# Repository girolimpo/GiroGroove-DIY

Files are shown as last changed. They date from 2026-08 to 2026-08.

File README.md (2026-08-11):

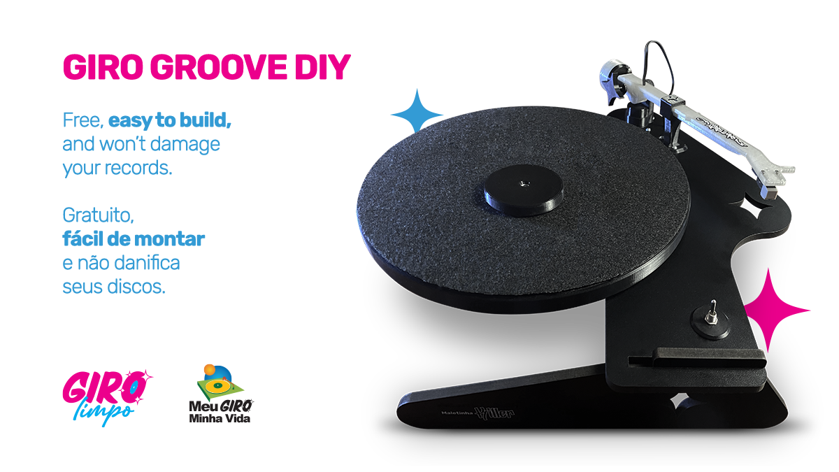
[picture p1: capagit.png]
Giro Groove DIY


# Giro Groove DIY
**A Giro Limpo project — [girolimpo.com.br](https://girolimpo.com.br)**

**A simple, functional and easy-to-build DIY turntable.**

The GiroGroove DIY is a project developed by **Giro Limpo** for anyone who wants to build their own turntable.

## Files

The files provided in this repository are final production-ready files.

* **BOM** — bill of materials and parts list
* **STL** — 3D printing files
* **CORTE_LASER** — PDF files for laser cutting
* **STROB_PROTRACT** — PDF file for cartridge calibration and turntable speed

## Assembly Tutorial

Follow the complete step-by-step assembly tutorial on YouTube:

**[▶ WATCH THE FULL TUTORIAL](LINK_TO_YOUTUBE)**

## Important

The video tutorial contains the complete assembly instructions for the project.

We recommend watching the tutorial before starting the build.

## License

This project is licensed under:

**Creative Commons Attribution-NonCommercial-ShareAlike 4.0 International (CC BY-NC-SA 4.0)**

You may copy, modify and build the project for non-commercial purposes, provided that proper credit is given and adaptations are distributed under the same license.

**Commercial use and sale of the project or its parts are not permitted.**

© Giro Limpo - Wesley de Castro - Brazil

---

# Giro Groove DIY
**Um projeto Giro Limpo — [girolimpo.com.br](https://girolimpo.com.br)**

**Um toca-discos DIY simples, funcional e fácil de montar.**

O GiroGroove DIY é um projeto desenvolvido pela **Giro Limpo** para quem quer construir seu próprio toca-discos.

## Arquivos

Os arquivos disponibilizados neste repositório são finais e estão prontos para produção.

* **BOM** — lista de materiais e peças
* **STL** — arquivos para impressão 3D
* **CORTE_LASER** — arquivos PDF para corte a laser
* **STROB_PROTRACT** — arquivo PDF para calibragem da cápsula e velocidade do prato

## Tutorial de montagem

Siga o passo a passo completo de montagem no YouTube:

**[▶ ASSISTA AO TUTORIAL COMPLETO](LINK_DO_YOUTUBE)**

## Importante

O tutorial em vídeo contém todas as instruções necessárias para a montagem do projeto.

Recomendamos assistir ao tutorial antes de iniciar a construção.

## Licença

Este projeto está licenciado sob:

**Creative Commons Attribution-NonCommercial-ShareAlike 4.0 International (CC BY-NC-SA 4.0)**

Você pode copiar, modificar e produzir o projeto para fins não comerciais, desde que atribua os devidos créditos e mantenha a mesma licença em eventuais adaptações.

**O uso comercial e a venda do projeto ou de suas partes não são permitidos.**

© Giro Limpo - Wesley de Castro - Brasil

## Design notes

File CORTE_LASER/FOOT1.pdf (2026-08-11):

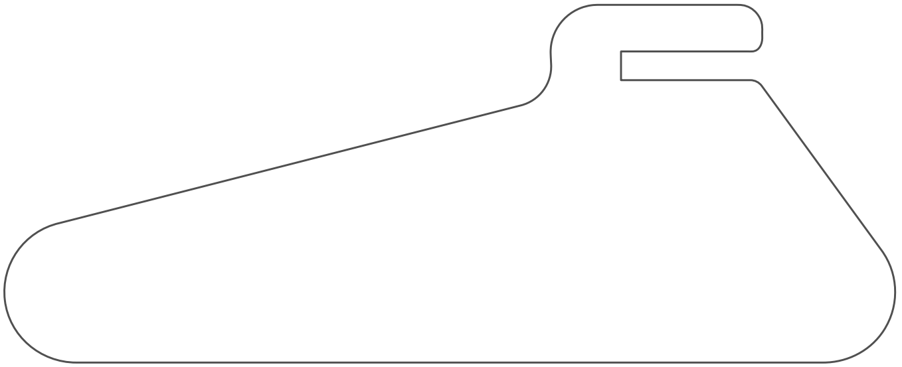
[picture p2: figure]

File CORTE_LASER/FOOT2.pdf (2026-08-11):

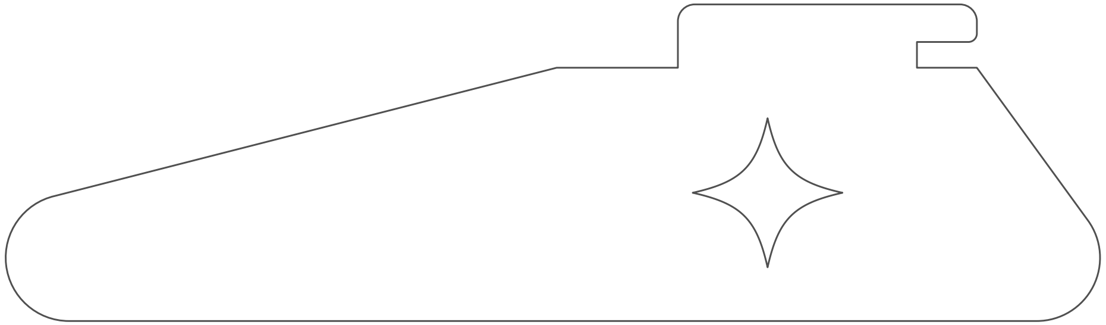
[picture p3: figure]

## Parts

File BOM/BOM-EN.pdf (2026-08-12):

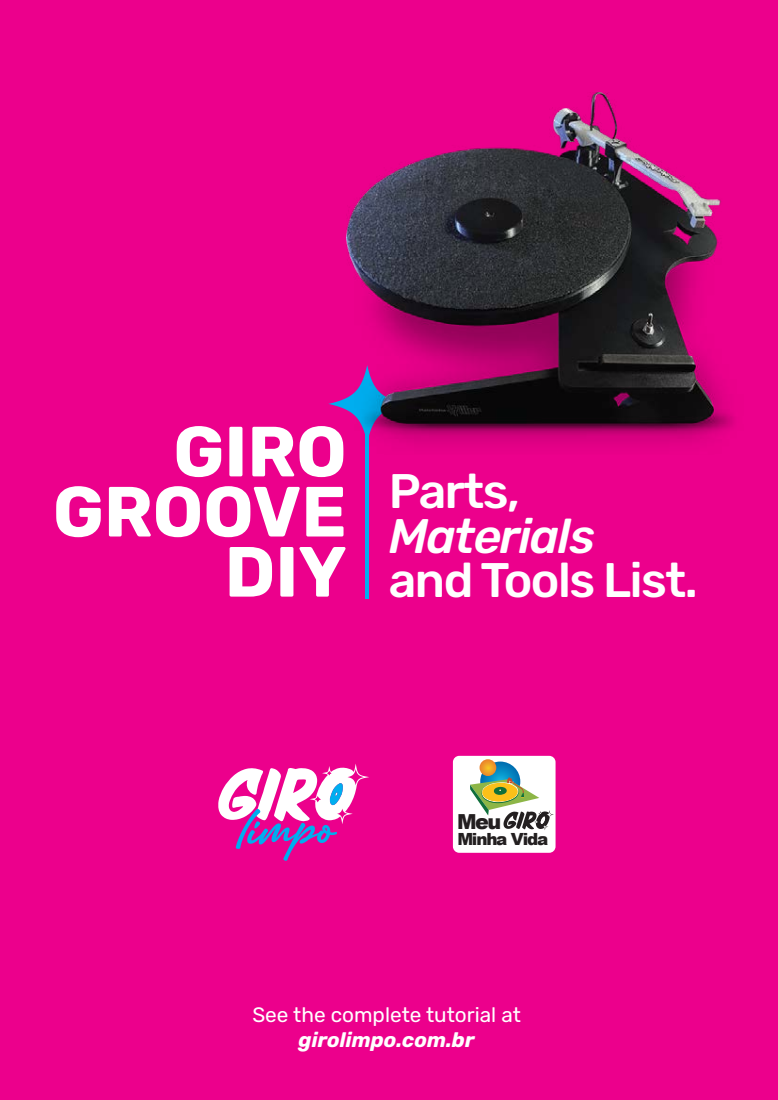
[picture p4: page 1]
Minha Vida; Meu; GIRO GROOVE DIY; Parts, Materials and Tools List.

See the complete tutorial at
girolimpo.com.br

# 3D PRINTER

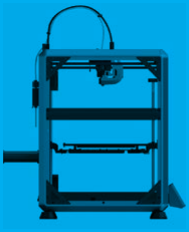
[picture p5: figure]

Recommended print area: approximately 30 × 30 cm
The project includes parts that need to be produced using 3D printing. A printer with a print area of approximately 30 × 30 cm will meet the project's needs well.
Don't have a 3D printer?
Don't worry. You probably know someone who does.
That friend who bought a 3D printer and now prints everything that comes along can finally be useful. Or look for a 3D printing service in your city — you don't need to own a machine to build your Giro Groove.

# LASER CUTTING

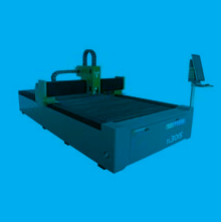
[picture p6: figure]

Some parts of the project are made from laser-cut MDF.
You don't need to buy a laser cutter — unless you're planning to start a business in this field.
Look for a laser cutting service in your city that works with MDF. Many companies accept digital files and deliver the parts already cut.
Tip: Search for “MDF laser cutting + your city name.”

# WIRE CUTTERS

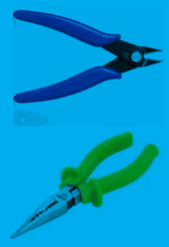
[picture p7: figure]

Used to cut wires and terminals and to make small finishing adjustments during assembly.

# NEEDLE-NOSE PLIERS

Very useful for holding components, bending terminals, and reaching hard-to-access areas.

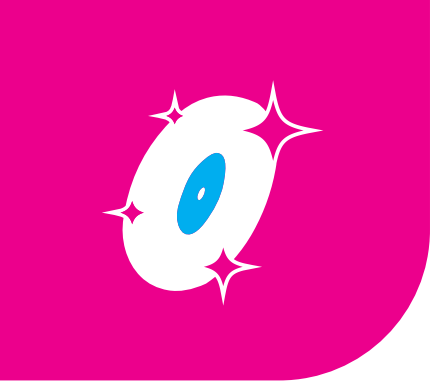
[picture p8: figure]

# Tools

You don't need a professional workshop to build the Giro Groove DIY. Some tools are essential, while others simply make the work easier — and some you can probably borrow, improvise, or easily find in your area.

# SOLDERING IRON

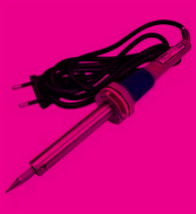
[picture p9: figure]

A simple 30 W or 40 W soldering iron is more than enough for this project.
There are only a few soldering points, and they are quite simple. Never soldered before?
This could be a great opportunity to learn. But if you prefer, any electronics repair shop can do the job in just a few minutes. Since there are only a few connections, the cost is usually very low.

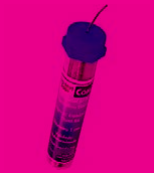
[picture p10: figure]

# ELECTRONICS SOLDER

Use solder specifically intended for electronics.
It will only be used for the electrical connections in the project.

# SCREWDRIVERS AND HEX KEYS

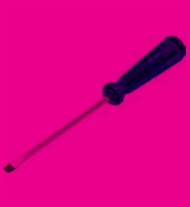
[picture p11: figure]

You will need the tools that match the screws you choose for the project.
They can be:
Flat-head screwdriver
Phillips screwdriver
Allen key
Or, if you prefer, a power screwdriver/drill with the corresponding bits. Besides speeding up the assembly, it also saves your arm some work.


# RUBBER MALLET

Not an essential tool, but it can be very helpful for some fittings, allowing you to apply light impacts without damaging the 3D-printed parts or the MDF.
If you don't have one, you will probably be able to assemble the project just fine without it.

correct model!

EG530SD-3F Turntable Motor

Flat drive belt for vinyl record

turntables, 5 mm × 190 mm
(measurement taken with
the belt folded in half).

# Electronic Components and Other Materials

Let's start with the MDF. The parts must be cut exactly to the dimensions specified in the original files available on GitHub, with no changes to their size. The MDF must be 4 mm thick.
You can use coated MDF, which provides a better finish and eliminates the need for painting. If you choose regular MDF, that's fine too: after cutting, you will only need to apply paint or whatever finish you prefer.
The 3D printing filament can be virtually any type, but for this project we recommend PETG because of its greater strength and durability. The color is entirely up to you. Choose the one that best matches your Giro Groove.
Most of the electronic components and other materials are easy to find. You can look for them at electronics stores, Mercado Livre, AliExpress, eBay, or any other supplier you prefer.
The following list is fully illustrated, with photos and specifications for each component, specifically to make identification easier and help you avoid buying a different part than the one required for the project.

# 3D Printing Filament and MDF

Make sure you
get the

DB15 female solder connector.; 12V 1A 12W power supply with P4 output.

AT3600L Moving Magnet Cartridge with Stylus for Turntables, or any other compatible cartridge you may have available. The better the cartridge, the better the sound quality of your Giro Groove DIY.

6202ZZ bearing, 15 × 35 × 11 mm.

608ZZ bearing, 8 × 22 × 7 mm.

625ZZ bearing, 5 × 16 × 5 mm.

DC-022 female P4 power jack, 5.5 × 2.1 mm, threaded.


Mini DPDT toggle switch, 6-pin, ON-OFF-ON.

2 metal male RCA plugs/connectors.

1 meter of Philips 2 × 0.50 mm² stereo audio cable.


60 cm of Philips 2 × 0.18 mm² stereo audio cable, or thinner.

12 × 3.0 × 12 mm self-tapping screws.

with 2 × 1/4" nuts.

1/4" × 1 1/4" hex bolt, black oxide, fully threaded,

1/4" × 5/8" hex bolt, black oxide.

25 machine screws with slotted, Allen, or Phillips heads. The head type does not matter, as long as you have the corresponding tool. What matters is that the screws are 15 mm long and, most importantly, have a 3 mm diameter.

### 2 M2.5 × 10 mm machine screws with M2.5 nuts for

cartridge mounting. If you cannot find the screws, you can use double-sided tape to attach the cartridge
to the headshell.

M18 hex nut for making the counterweight.

4 mm heat-shrink tubing.

# And for the adjustments?

### 50 cm of automotive carpet or felt for

making the slipmat.

Super glue, epoxy, Super Bonder, or another similar adhesive.


Stroboscopic disc for speed adjustment or a smartphone app to adjust the platter RPM.


Protractor alignment gauge for cartridge alignment, also available for download in the GitHub folder.

With all the components and materials gathered, don't forget the 3D-printed parts. There are 20 printed parts in total that make up the project.
You will also need the 3 MDF pieces, already cut according to the original files. Everything ready? Then it's time to get your hands dirty.
Visit girolimpo.com.br and head over to the Giro Limpo YouTube channel to follow the complete Giro Groove DIY tutorial.
And while you're there, take a moment to check out our store. If you'd like to support the project and help keep new projects like this coming, you can also contribute via PIX or PayPal.
And don't forget to like and follow the channel. It helps keep the project spinning.

And now, it's time to get started.

## girolimpo.com.br

© 2026 GIRO LIMPO. Wesley de Castro. All rights reserved.

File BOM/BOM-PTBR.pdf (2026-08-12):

Minha Vida; Meu; GIRO GROOVE DIY; Lista de peças, materiais e ferramentas

Veja o Tutorial completo
no site girolimpo.com.br

# IMPRESSORA 3D


Área de impressão recomendada: aproximadamente 30 × 30 cm O projeto possui peças que precisam ser produzidas em impressão 3D. Uma impressora com uma área de impressão de aproximadamente 30 × 30 cm atende bem às necessidades do projeto.
Não tem uma impressora 3D?
Calma. Você certamente conhece alguém que tem.
Aquele amigo que comprou uma impressora 3D e agora imprime tudo o que aparece pode finalmente ser útil. Ou procure um serviço de impressão 3D na sua cidade — você não precisa ter uma máquina em casa para construir o seu Giro Groove.


# CORTE A LASER

Algumas peças do projeto são produzidas em MDF cortado a laser. Você não precisa comprar uma máquina de corte dessa — a menos que esteja planejando abrir um negócio nesse ramo. Procure na sua cidade por um bureau de corte a laser que trabalhe com MDF. Existem muitas empresas que recebem os arquivos digitalmente e entregam as peças já cortadas. Dica: pesquise por “corte a laser MDF + nome da sua cidade.

# ALICATE DE CORTE


Utilizado para cortar fios, terminais e realizar pequenos acabamentos durante a montagem.

# ALICATE DE PONTA

Muito útil para segurar componentes, dobrar terminais e alcançar locais de difícil acesso.


# Ferramentas

Você não precisa de uma oficina profissional para construir o Giro Groove DIY. Algumas ferramentas são indispensáveis, outras apenas facilitam o trabalho — e algumas você provavelmente consegue emprestadas, improvisadas ou encontra facilmente na sua cidade.

# FERRO DE SOLDA


Um ferro de solda simples de 30 W ou 40 W já atende perfeitamente ao projeto.
As soldagens são poucas e bastante simples.
Nunca soldou antes?
Essa pode ser uma ótima oportunidade para aprender. Mas, se preferir, qualquer oficina de eletrônica faz esse serviço em poucos minutos e, por serem apenas algumas conexões, o custo costuma ser bem baixo.


# SOLDA PARA ELETRÔNICA

Utilize solda de estanho própria para eletrônica.
Ela será usada apenas nas conexões elétricas do projeto.

# CHAVES DE MONTAGEM


Você precisará das chaves compatíveis com os parafusos escolhidos para o projeto.
Pode ser:
Chave de fenda
Chave Phillips
Chave Allen
Ou, se preferir, uma parafusadeira com os bits correspondentes. Além de agilizar a montagem, ela ainda poupa um pouco o braço.


# MARTELO DE BORRACHA

Não é uma ferramenta obrigatória, mas ajuda bastante em alguns encaixes, permitindo aplicar pequenos impactos sem danificar as peças impressas ou o MDF.
Se não tiver um, provavelmente conseguirá montar o projeto da mesma forma.


Motor para toca-discos
EG530SD-3F.

Correia de transmissão plana para

toca-discos de vinil, 5 mm × 190 mm (medida feita com a correia dobrada).

# Componentes eletrônicos e outros materiais

Começamos pelo MDF. As peças devem ser cortadas exatamente nas medidas dos arquivos originais disponibilizados no GitHub, sem alterações de tamanho. O MDF deve ter 4 mm de espessura.
Você pode utilizar MDF revestido, o que proporciona um acabamento melhor e evita a necessidade de pintura. Se optar pelo MDF comum, não tem problema: depois do corte, será necessário apenas algum tipo de pintura ou acabamento de sua preferência.
O filamento utilizado na impressão 3D pode ser de praticamente qualquer tipo, mas para este projeto recomendamos o PETG pela sua maior resistência e durabilidade. A cor fica totalmente a seu critério. Pode escolher a que mais combina com o seu Giro Groove.
Os componentes eletrônicos e demais materiais são, em sua maioria, fáceis de encontrar. Você pode procurar em lojas de eletrônica, Mercado Livre, AliExpress, eBay ou em outros fornecedores de sua preferência.
A lista a seguir é toda ilustrada, com fotos e especificações dos componentes, justamente para facilitar a identificação e evitar que você compre uma peça diferente da necessária para o projeto.

# Filamento 3D e MDF

Atenção para
o modelo correto!

Conector DB15 fêmea para solda.

Cartucho magnético móvel AT3600L com agulha para toca-discos Audio Technica ou alguma outra que você tenha disponível. Quanto melhor o cartucho melhor a qualidade sonora do seu Giro Groove DIY.

Fonte de alimentação 12 V, 1 A, 12 W, com saída P4.

Rolamento 6202ZZ, 15 × 35 × 11 mm.

Rolamento 608ZZ, 8 x 22 x 7 mm.

Rolamento 625ZZ, 5 x 16 x 5 mm.

Conector jack P4 fêmea DC-022, 5,5 × 2,1 mm, com rosca.


Mini chave toggle switch DPDT, 6 pinos, ON-OFF-ON.

2 plugs RCA macho metálicos (conectores RCA).

### 1 metro de cabo de áudio estéreo duplo

Philips 2 × 0,50 mm².


### 60 centímetros de cabo de áudio estéreo duplo Philips

2 × 0,18 mm² ou mais fino.

12 parafusos de rosca soberba 3,0 × 12 mm.

de 2 porcas 1/4"

Parafuso sextavado 1/4" × 1 1/4", preto oxidado, com rosca em todo o comprimento e acompanhado

Parafuso sextavado 1/4" × 5/8", preto oxidado.

25 parafusos tipo máquina, com cabeça fenda, Allen ou Phillips. O tipo de cabeça não importa, desde que você tenha a chave correspondente.
O importante é que o parafuso tenha 15 mm de comprimento e, principalmente, 3 mm de diâmetro.

2 parafusos de máquina M2,5 × 10 mm, com porcas M2,5, para fixação da cápsula. Caso não encontre os parafusos, você pode utilizar fita dupla face para fixar a cápsula
à headshell.

Porca sextavada M18 para confecção do contrapeso.

# E para fazer os ajustes?

### 50 cm de carpete automotivo ou feltro para

a confecção do slipmat.

Supercola, epóxi, Super Bonder ou outro adesivo semelhante.

Espaguete termo retrátil de 4 mm.


Disco estroboscópico para ajuste da velocidade ou aplicativo para smartphone para ajustar
o RPM do prato.


Régua Protractor para alinhamento da cápsula, também disponível para download na pasta do GitHub.

Com os componentes e materiais reunidos, não esqueça das peças impressas em 3D. Ao todo, são 20 peças que fazem parte do projeto.
Você também precisará das 3 peças de MDF, já cortadas conforme os arquivos originais.
Tudo pronto? Então é hora de colocar a mão na massa.
Acesse o site girolimpo.com.br e entre no canal do Giro Limpo no YouTube para acompanhar o tutorial completo do Giro Groove DIY.
E já que você está por lá, aproveite para conhecer a nossa loja. Se quiser apoiar o projeto e ajudar a manter novos projetos como este acontecendo, você também pode contribuir através do PIX ou PayPal.
E não esqueça de curtir e seguir o canal. Isso ajuda o projeto a continuar girando.

# E agora, é hora de começar

## girolimpo.com.br

© 2026 GIRO LIMPO. Wesley de Castro. Todos os direitos reservados.

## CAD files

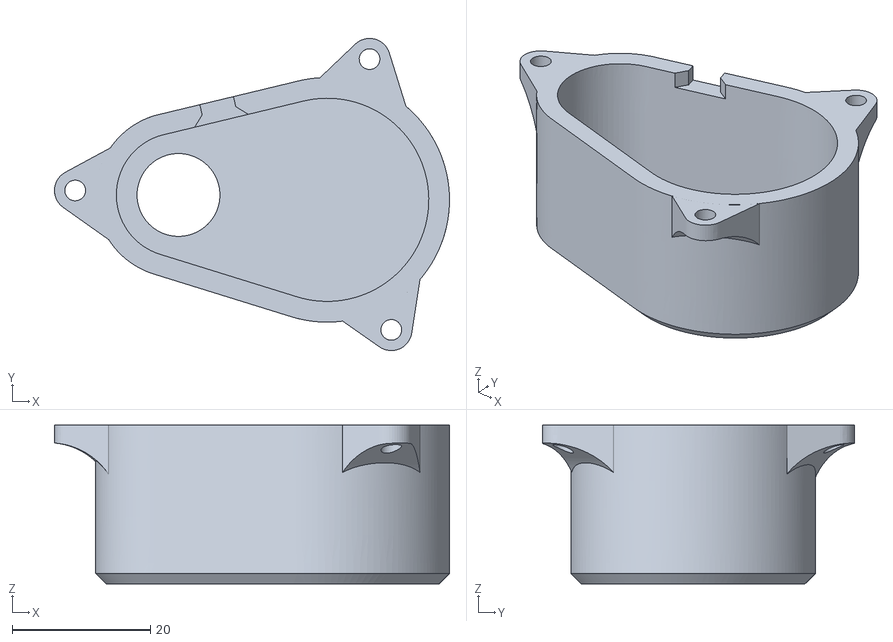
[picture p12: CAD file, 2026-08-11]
STL/powerbox.stl
57.2 x 45.2 x 23.0

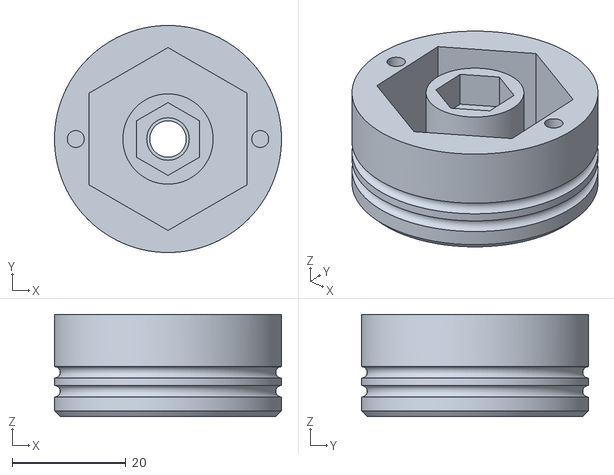
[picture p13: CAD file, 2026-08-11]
STL/contrapeso.stl
40.0 x 40.0 x 18.0

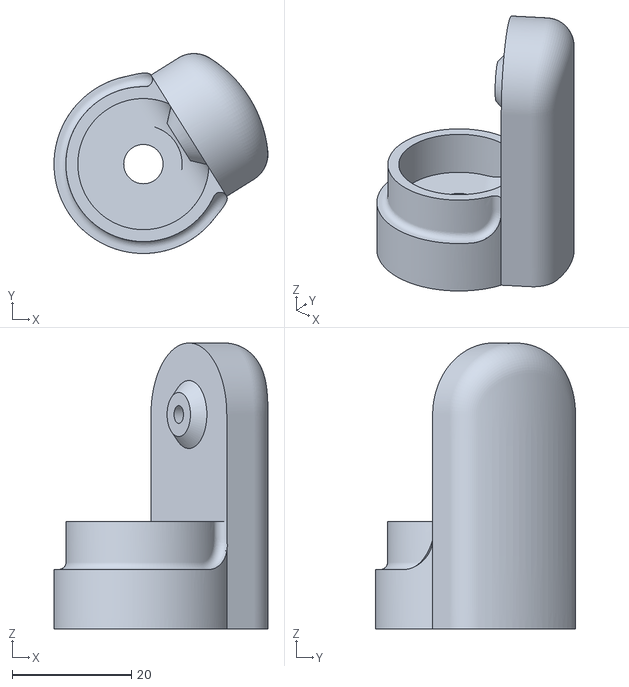
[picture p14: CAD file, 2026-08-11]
STL/basebraco2.stl
35.9 x 33.6 x 48.0

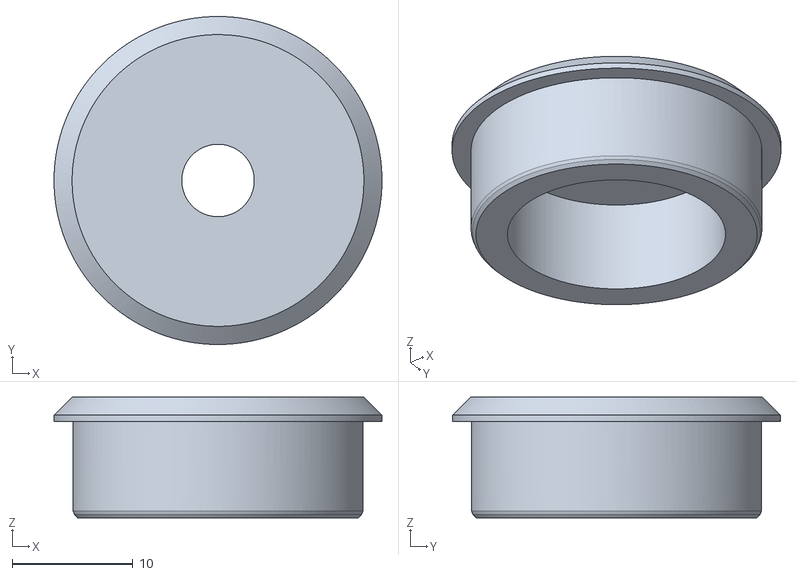
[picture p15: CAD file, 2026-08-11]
STL/onoff.stl
27.1 x 27.1 x 10.0

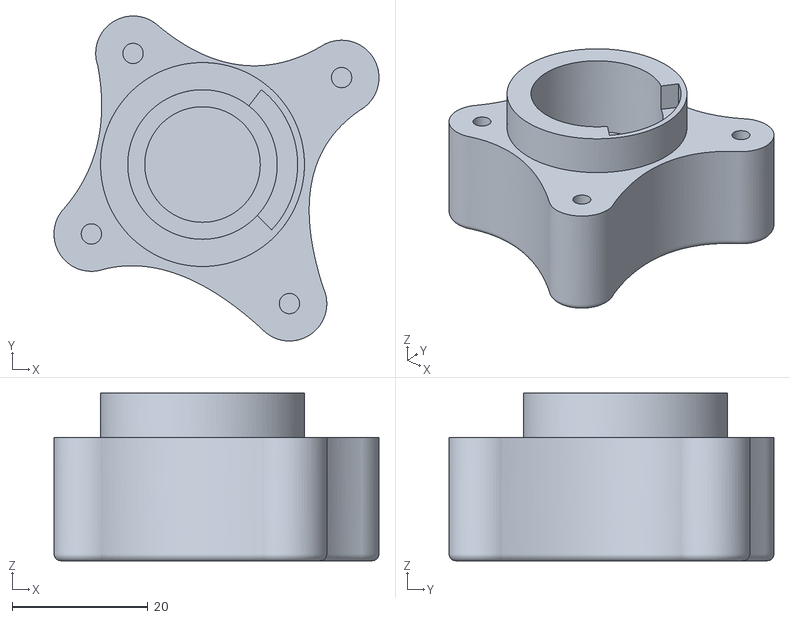
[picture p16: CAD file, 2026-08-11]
STL/basebraco.stl
47.8 x 47.8 x 24.7

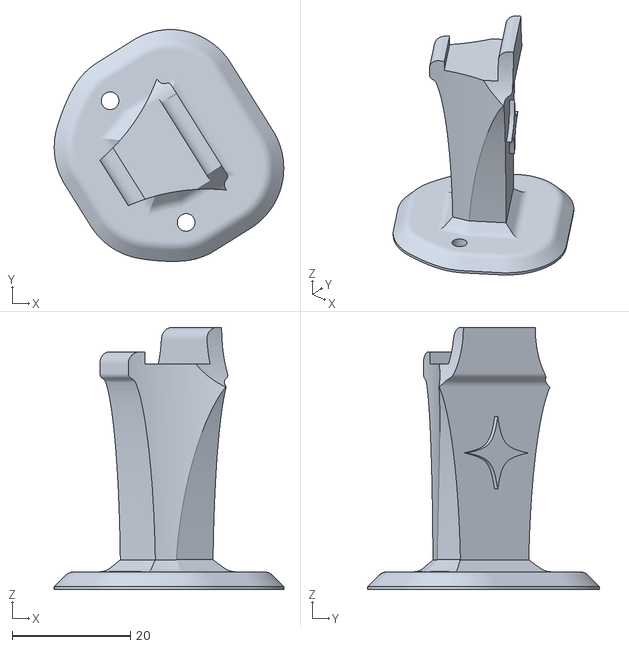
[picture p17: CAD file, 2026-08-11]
STL/apoiobraco.stl
38.9 x 39.2 x 44.4

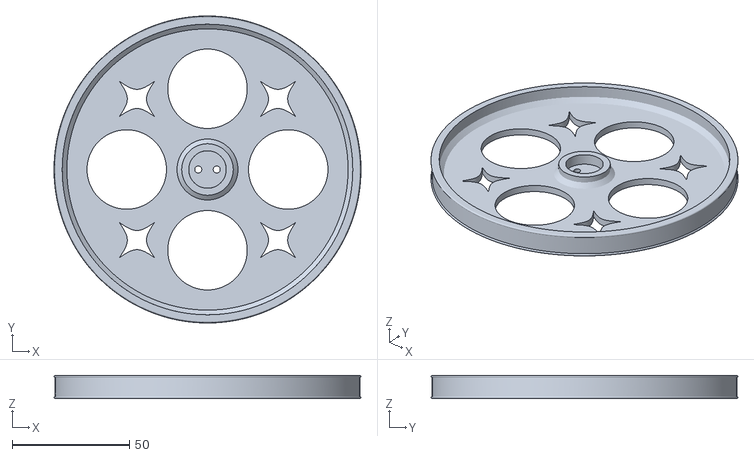
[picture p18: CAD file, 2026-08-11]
STL/roldanaprato.stl
131.0 x 131.0 x 9.99

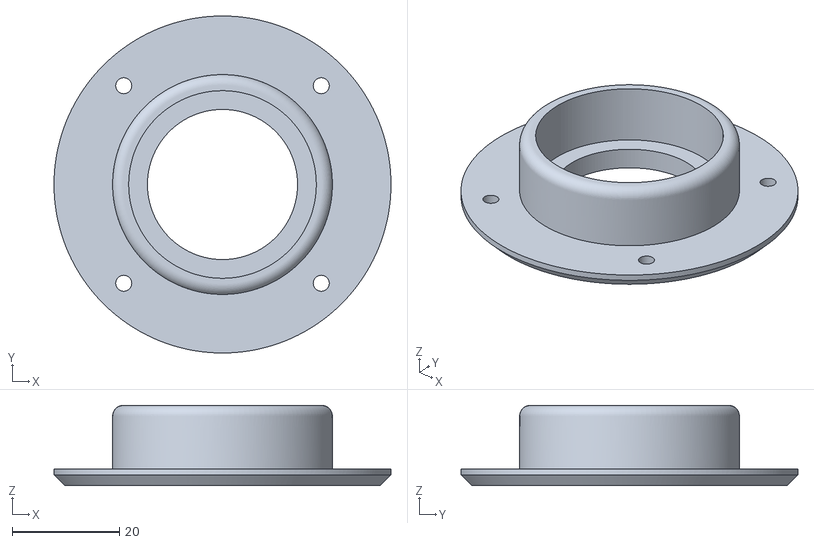
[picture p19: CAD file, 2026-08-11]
STL/rolamento.stl
62.9 x 62.9 x 15.0

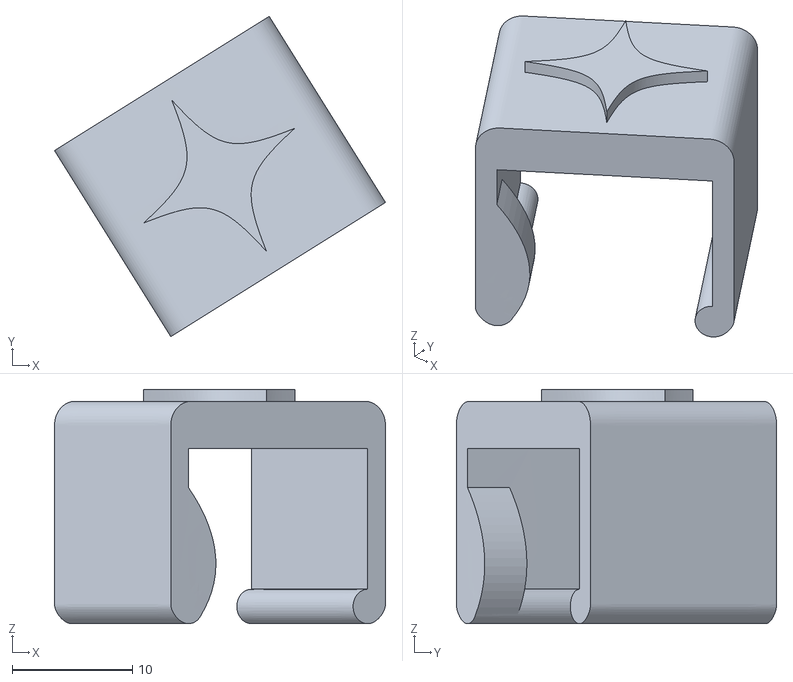
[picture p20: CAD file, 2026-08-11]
STL/travabraco.stl
27.5 x 26.6 x 19.5

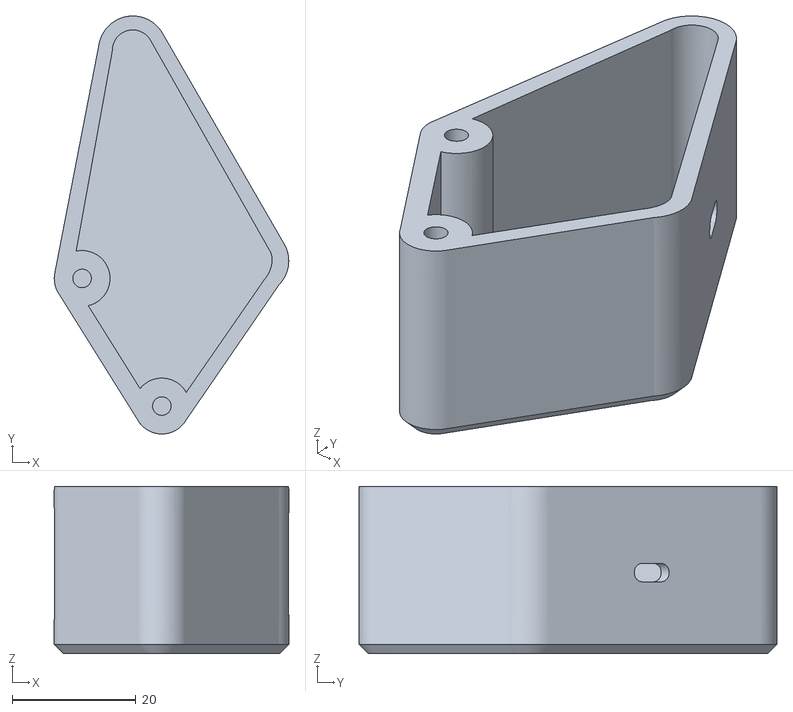
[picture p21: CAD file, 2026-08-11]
STL/audioout.stl
37.8 x 67.4 x 27.0

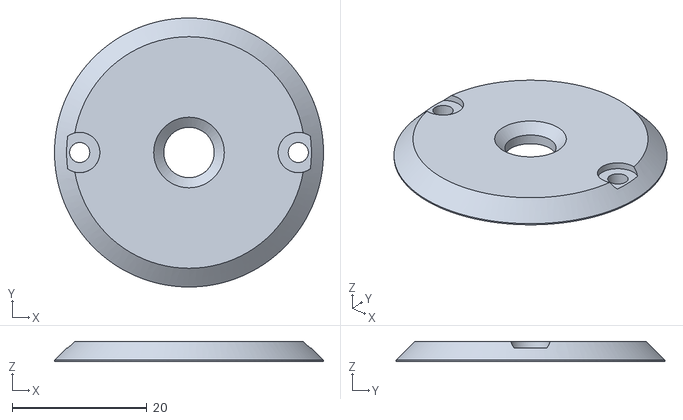
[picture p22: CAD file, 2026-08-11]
STL/tampacontrapeso.stl
40.0 x 40.0 x 2.98

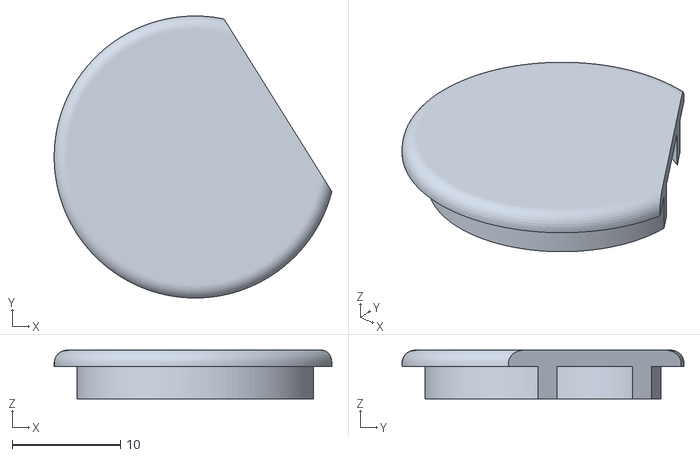
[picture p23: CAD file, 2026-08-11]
STL/tampabraco.stl
25.6 x 26.0 x 4.50

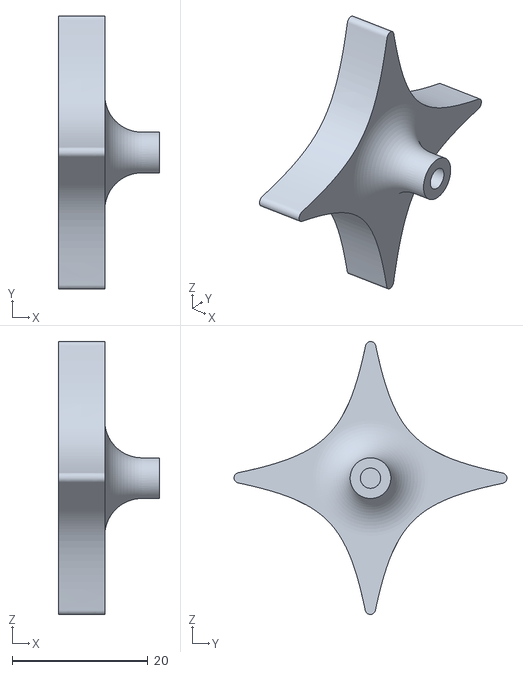
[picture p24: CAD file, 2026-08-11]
STL/estrela.stl
14.9 x 40.3 x 40.3

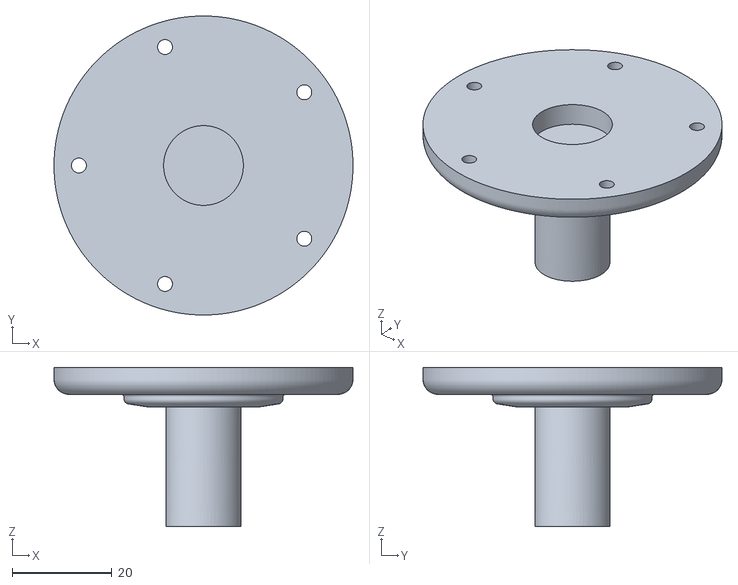
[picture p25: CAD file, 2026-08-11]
STL/baseprato.stl
60.0 x 60.0 x 32.0

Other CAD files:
STL/motorcurto.stl
STL/braco.stl
STL/baseestrela.stl
STL/motorlongo.stl

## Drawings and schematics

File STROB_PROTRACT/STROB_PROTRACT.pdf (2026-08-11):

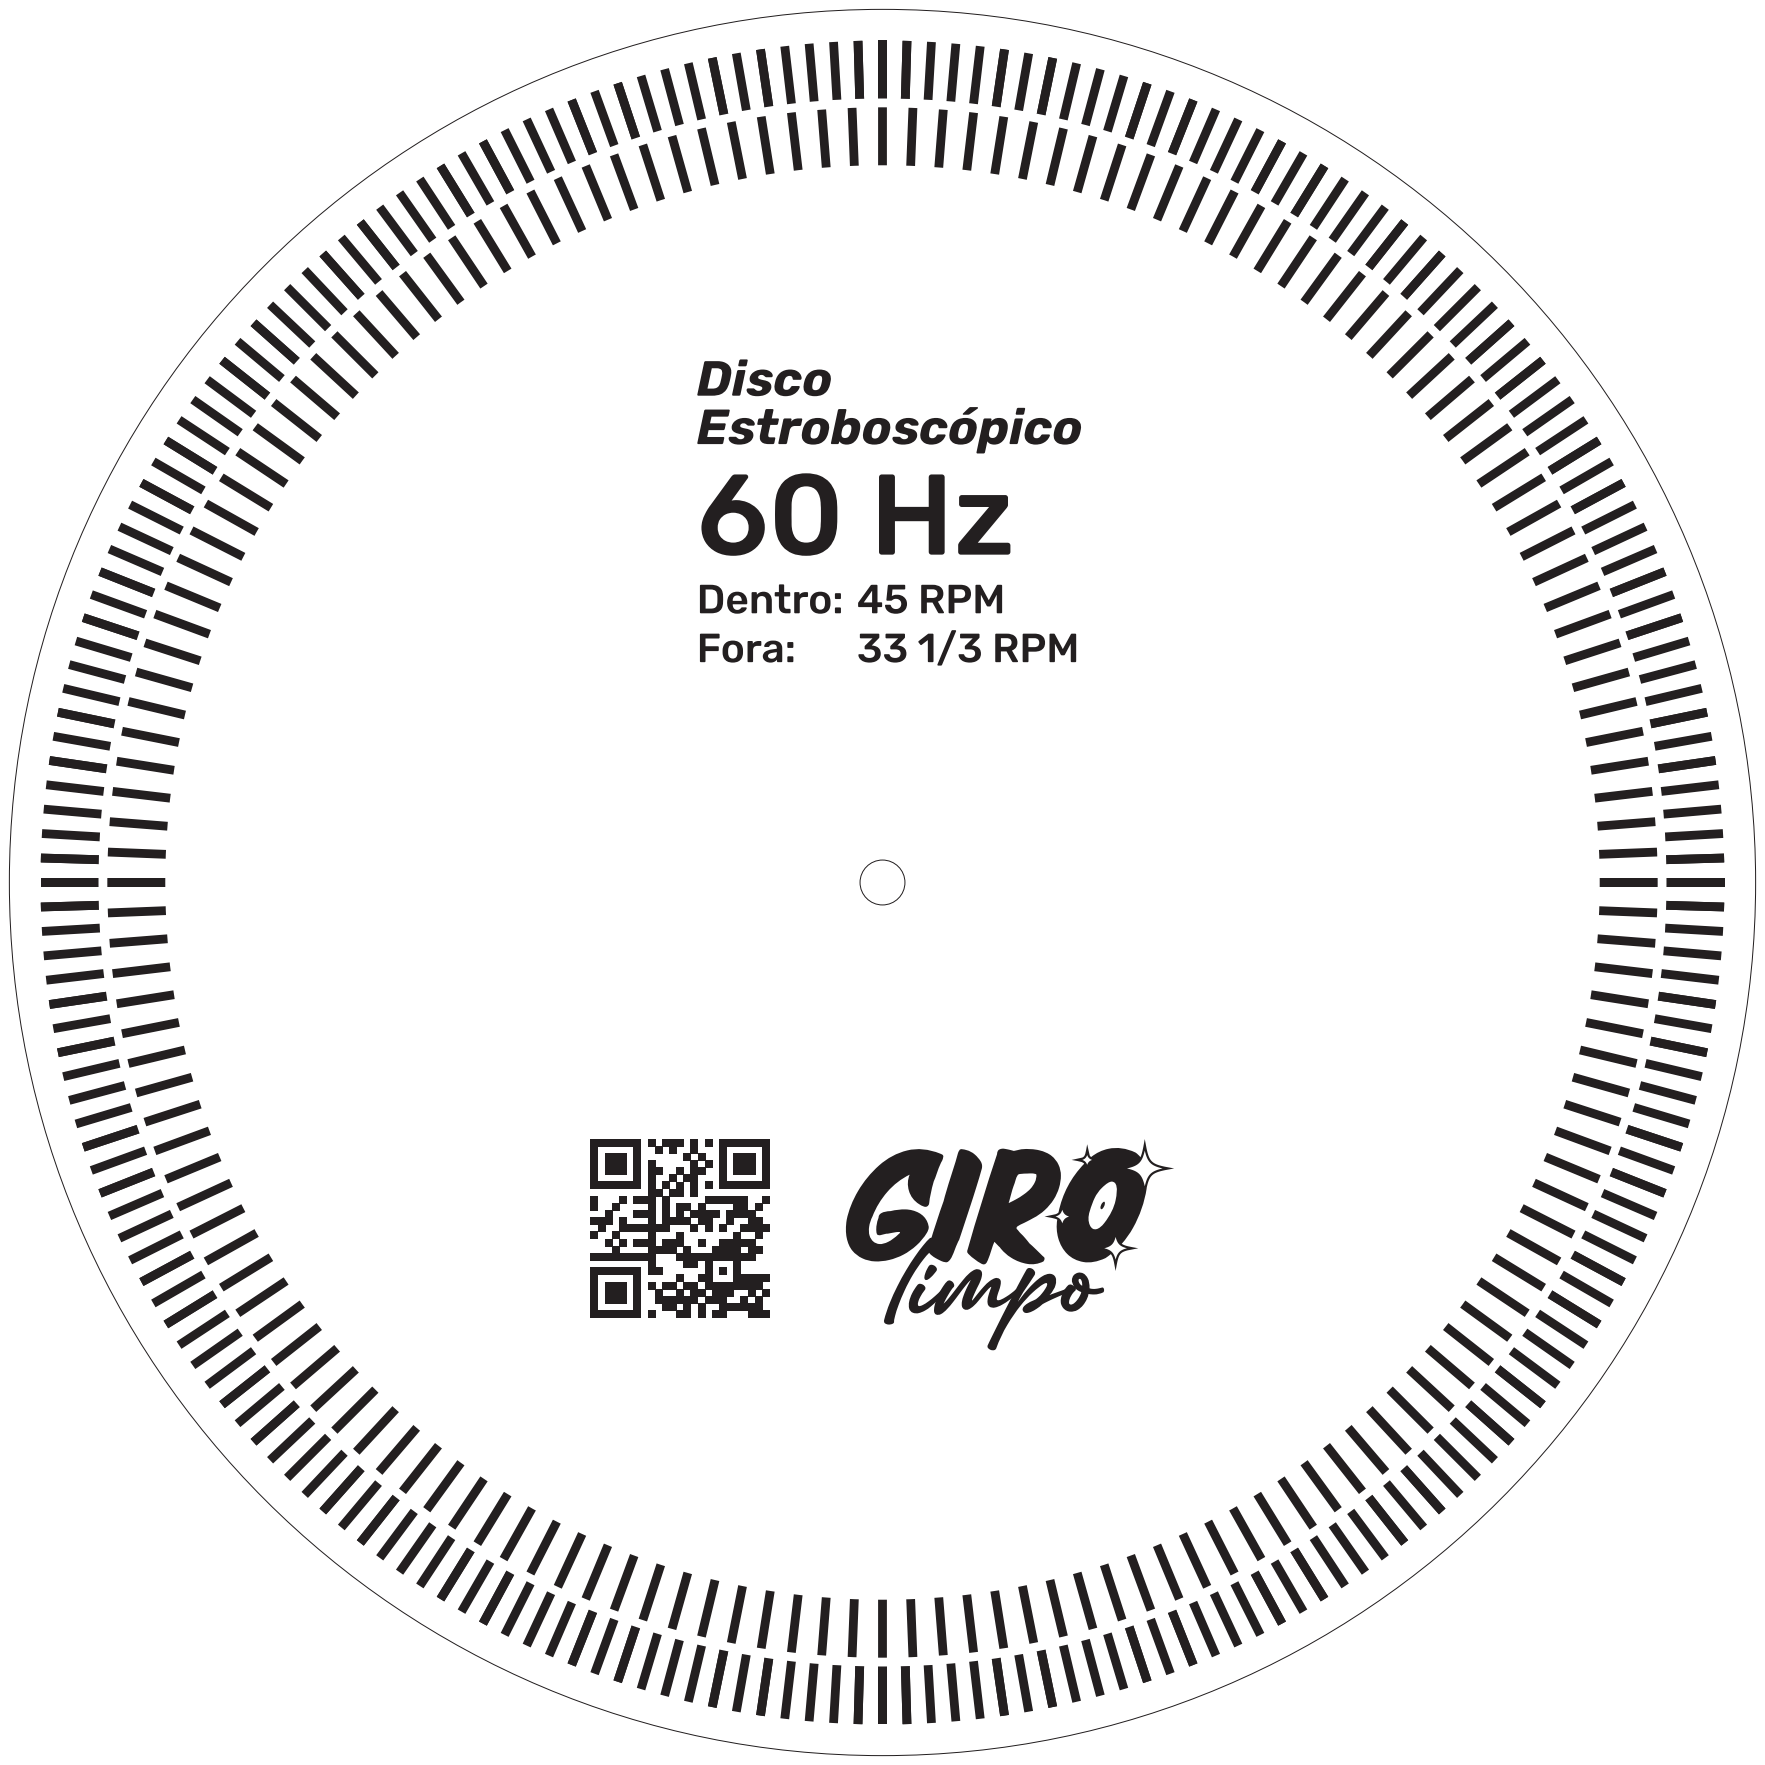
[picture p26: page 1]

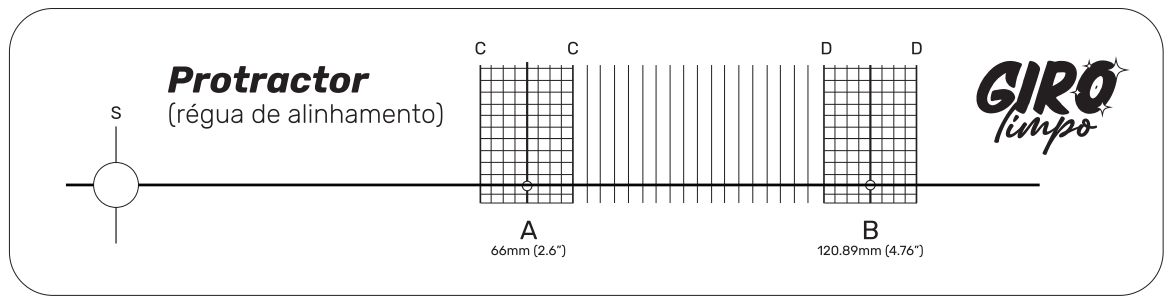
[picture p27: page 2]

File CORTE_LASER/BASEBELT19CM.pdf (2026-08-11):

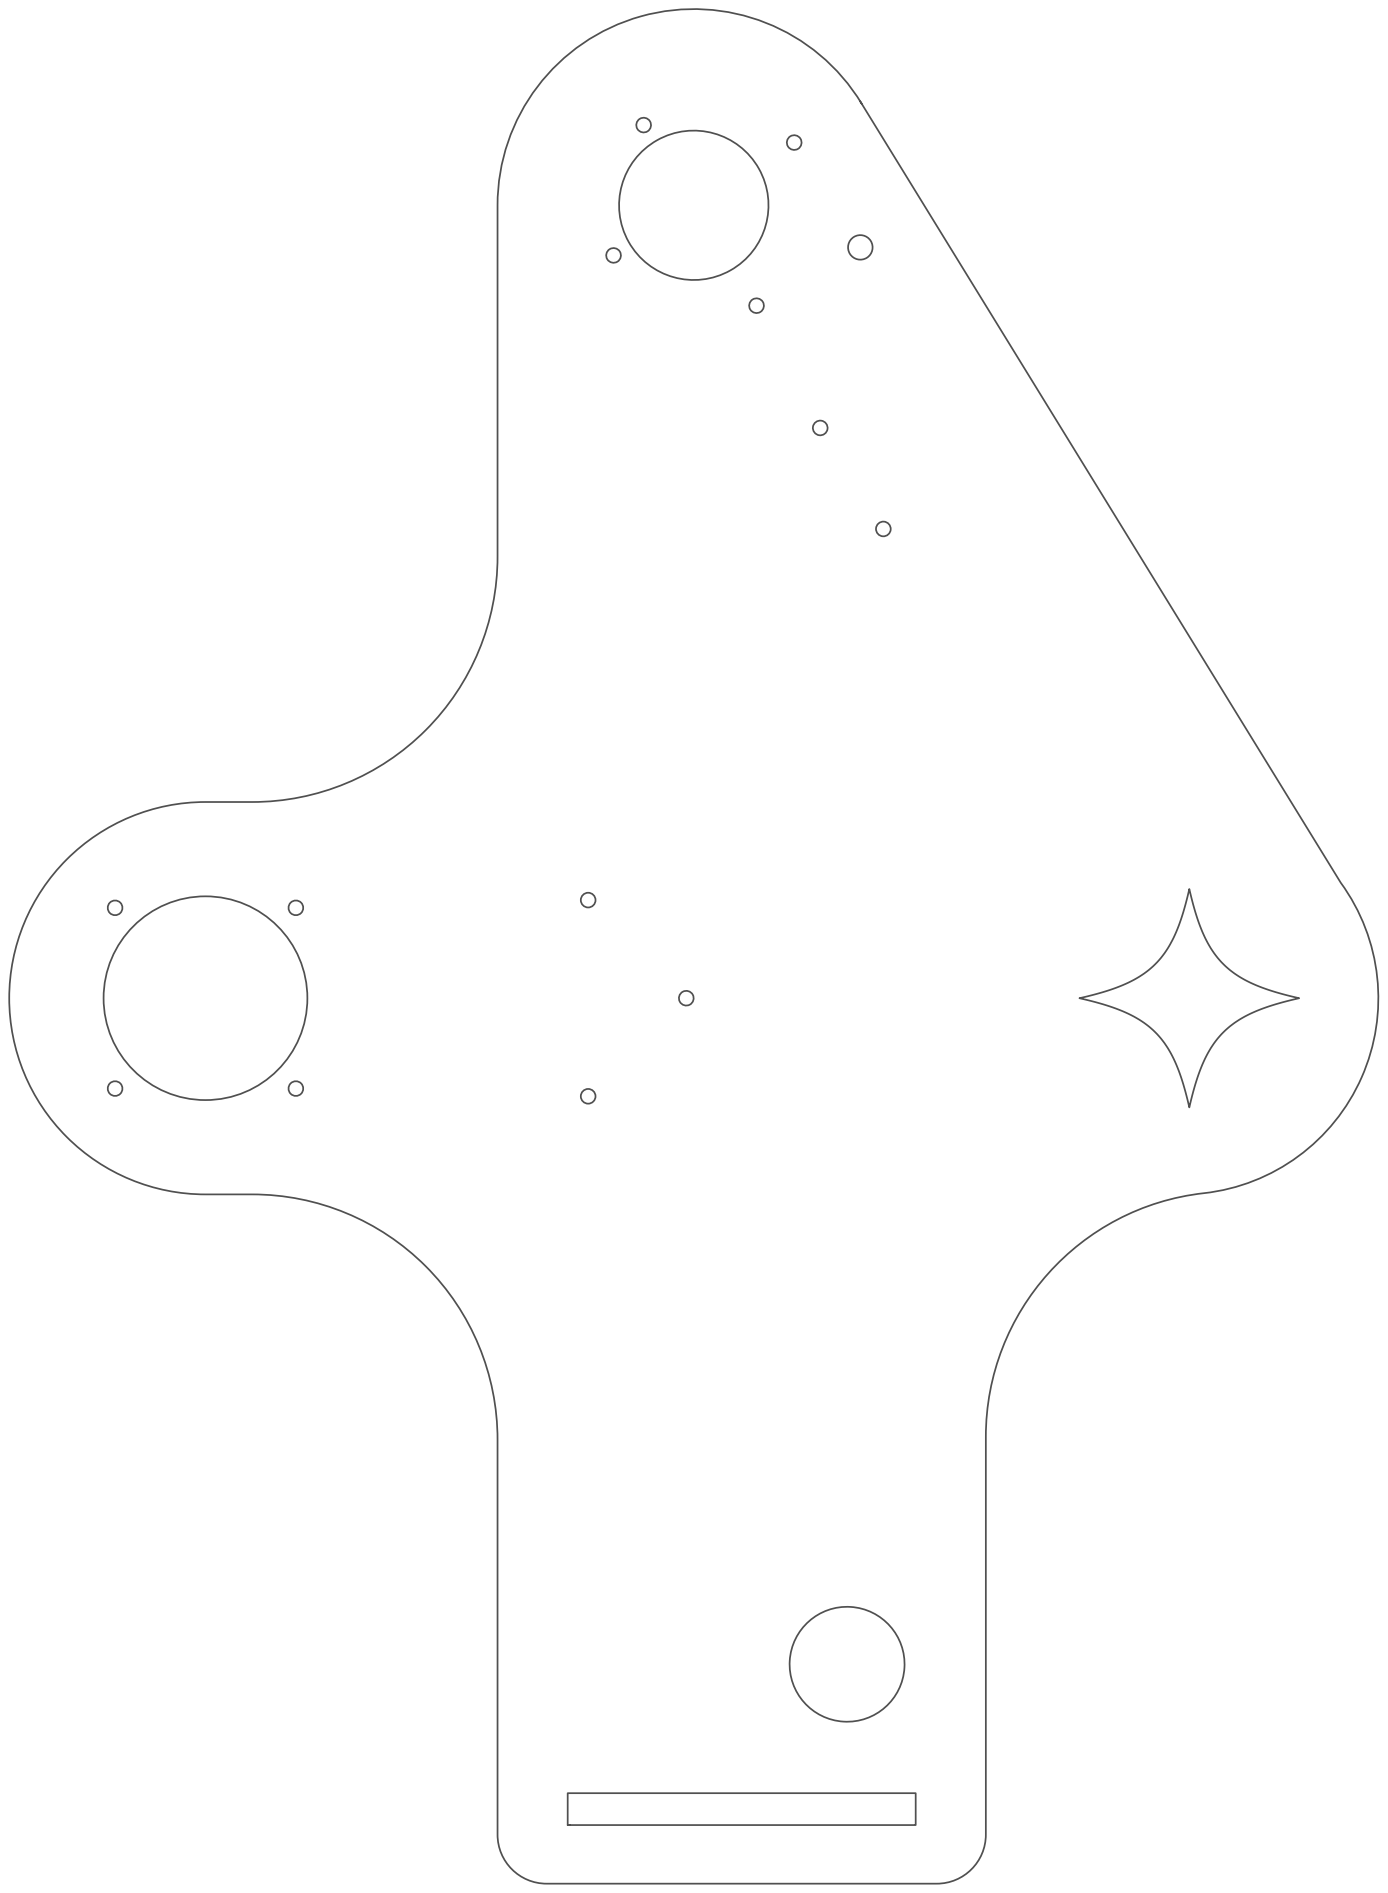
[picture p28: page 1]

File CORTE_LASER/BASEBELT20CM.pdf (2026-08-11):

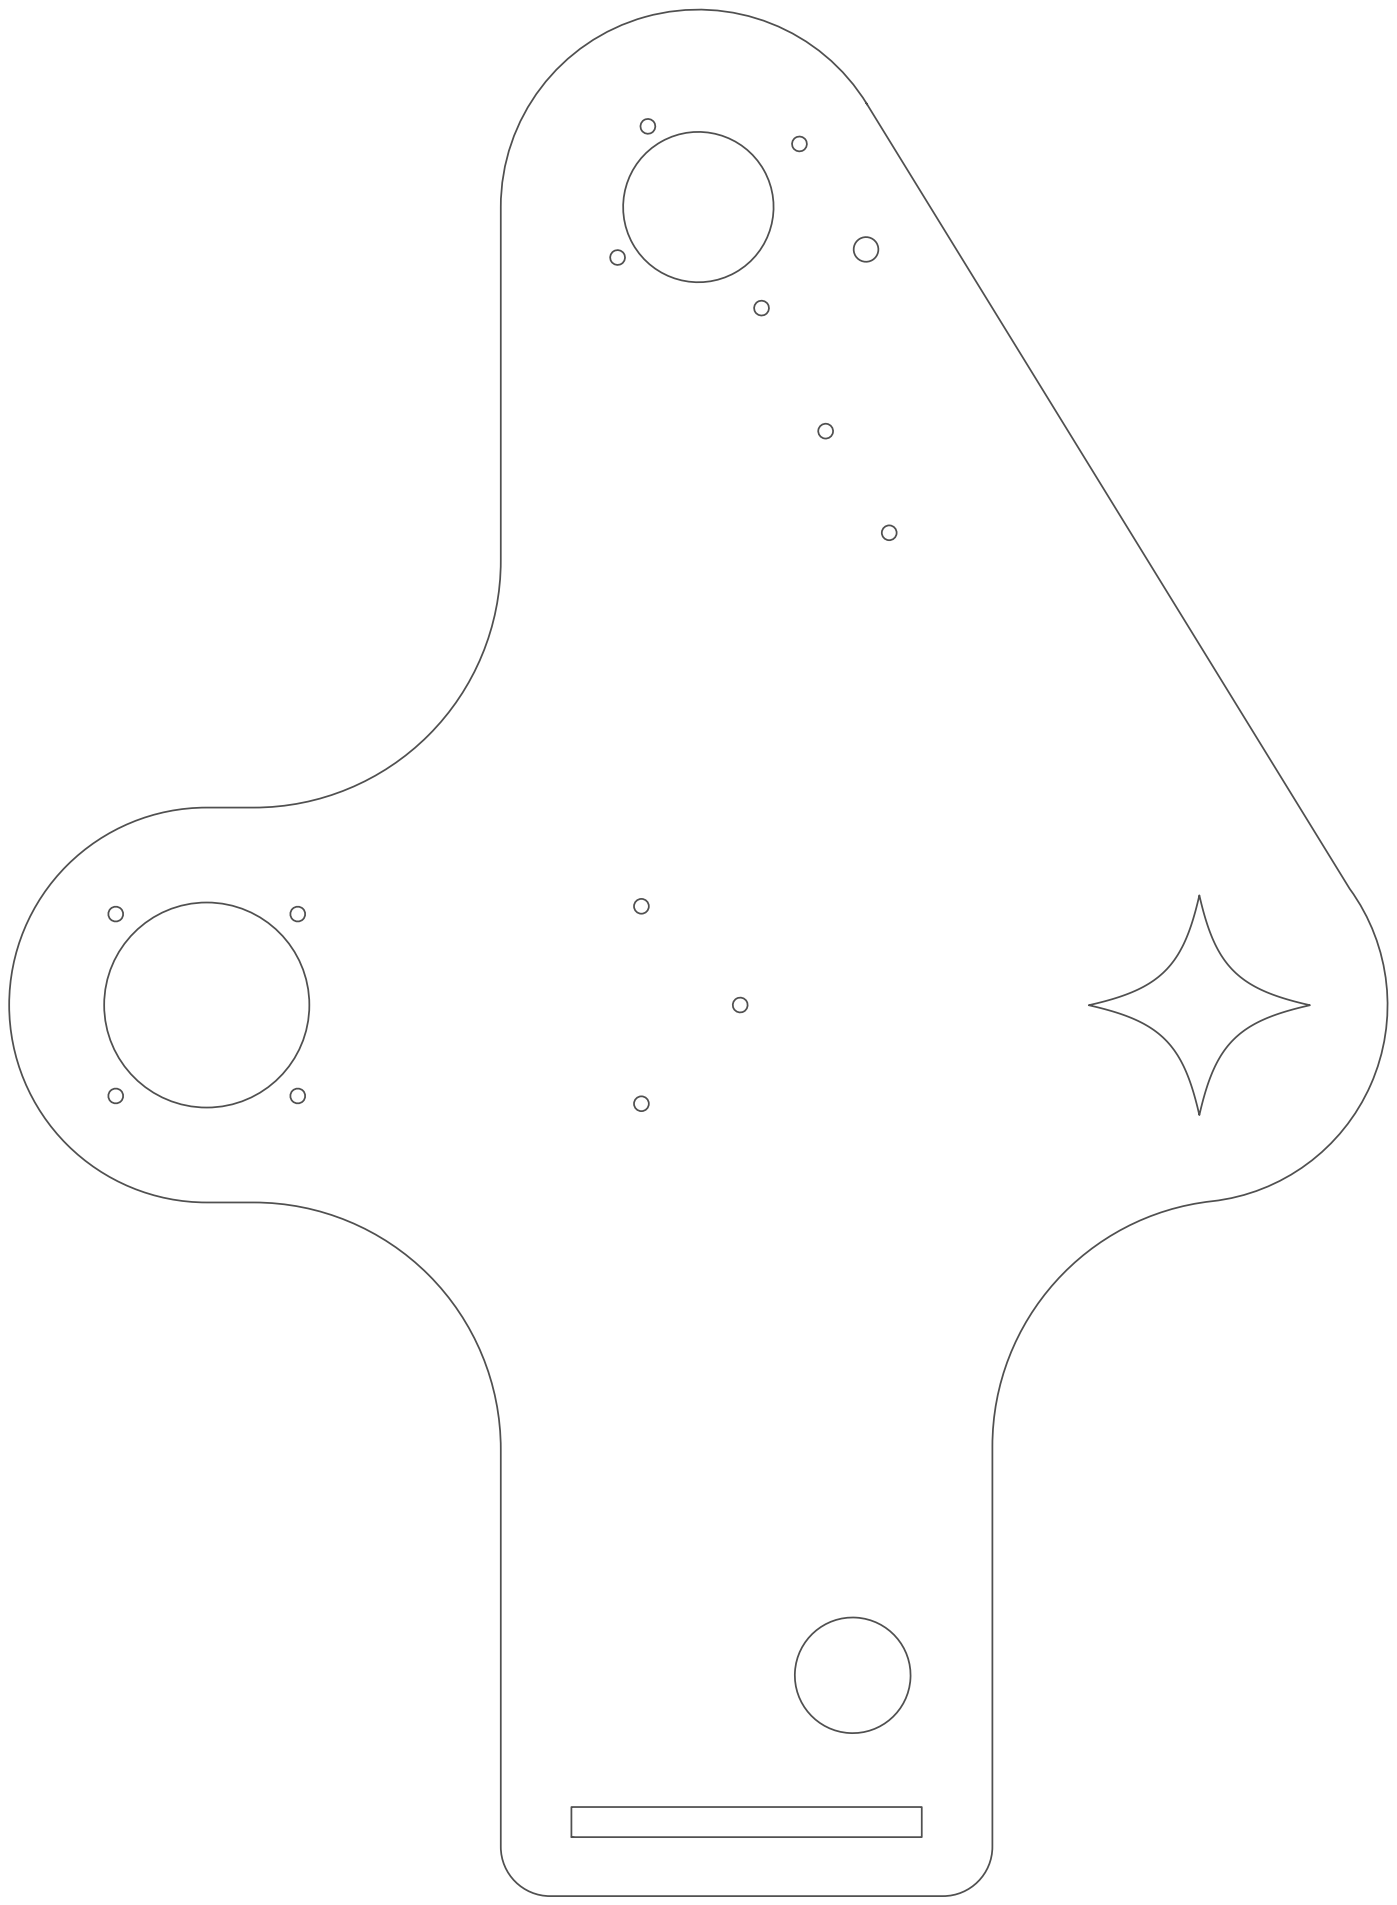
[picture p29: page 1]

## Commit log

2026-08-06 Remove emojis from assembly tutorial headings
2026-08-06 Rename LASER_CUT to CORTE_LASER in README
2026-08-11 Add STROB_PROTRACT PDF file details to README
    Added information about the STROB_PROTRACT PDF file for cartridge calibration and turntable speed in both English and Portuguese sections.
